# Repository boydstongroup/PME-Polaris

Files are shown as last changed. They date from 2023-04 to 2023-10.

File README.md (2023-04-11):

#Polaris PME 3D Printer Conversion Guide

This repository contains the necessary files and instructions to convert a Creality Ender-3 FFF 3D printer into an open-source Powder Melt Extrusion (PME) 3D printer.

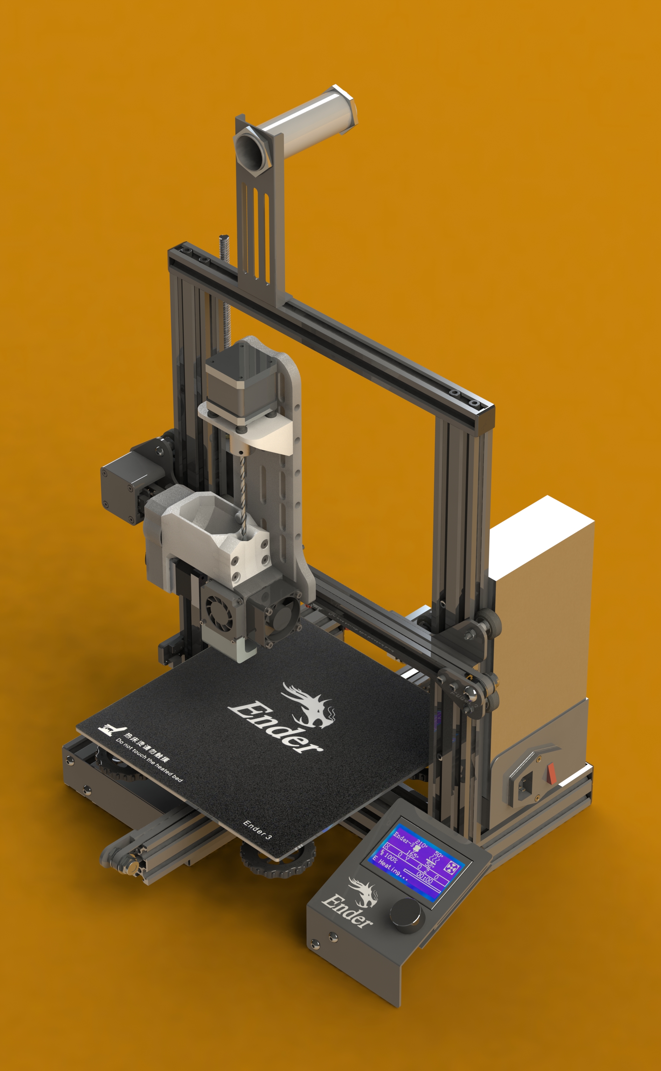
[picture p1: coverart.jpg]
PME rendering


## Table of Contents

- [Introduction](#introduction)
- [Prerequisites](#prerequisites)
- [Conversion Process](#conversion-process)
- [Contribution](#contribution)

## Introduction

The Polaris PME 3D printer enables the use of custom materials without the need for expensive filamentation processes. It also facilitates recycling and compositing of bespoke polymers with specific physical or chemical properties. The conversion process involves 3D printing custom parts, soldering electrical components, and assembling the printer. This guide aims to help researchers and enthusiasts modify a Creality Ender-3 FFF 3D printer to build an affordable and reliable PME printing system.

## Prerequisites

- Access to a functioning FFF 3D printer (for printing custom parts)
- Necessary parts and tools as specified in the bill of materials
- Basic technical knowledge (soldering, assembling, etc.)

## Conversion Process

1. Clone the [PME-Polaris repository](https://github.com/boydstongroup/PME-Polaris.git) and explore the README file for detailed information about the bill of materials and 3D models.
2. Print the custom parts using the provided 3D models.
3. Gather all necessary components and tools.
4. Follow the step-by-step conversion guide to assemble your Polaris PME 3D printer.
5. Set up the firmware and software for the printer.
6. Test and calibrate the PME 3D printer according to the provided instructions.

## Contribution

The PME project is actively developed, and contributions from the open-source community are welcome. We encourage researchers and enthusiasts to modify, improve, and share their work to advance the field of 3D printing. If you have any questions, suggestions, or improvements, please submit an issue or pull request to the [PME-Polaris repository](https://github.com/boydstongroup/PME-Polaris.git).

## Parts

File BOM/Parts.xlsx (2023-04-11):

Necessary parts
Name: | Count: | Suggested Link:
4mm Long Wood Drill | 1 | https://a.co/d/aSQy0m2
4mm to 5mm Flexible Shaft Coupling | 1 | https://a.co/d/cc4Hip7
Nema 17 Stepper Motor | 2 | https://a.co/d/9WOH7OL
M3 Rubber Damper | 4 | https://a.co/d/5EjhD60
M3x20mmMale to Female Brass Spacer | 2 | https://a.co/d/1yBfoaK
Arduino UNO R3 | 1 | https://a.co/d/0CqywGE
12mm 5V Active Piezo Buzzer | 1 | https://a.co/d/2qRS85m
I2C 1602 LCD Display Screen | 1 | https://a.co/d/4X4S6Zm
8 Pins Single Row Female Pin Headers | 2 | https://a.co/d/d53gv55
40 pin Breakable Pin Header | 1 | https://a.co/d/14hLw99
360 Degree Rotary Encoder Module | 1 | https://a.co/d/fJl5Fw0
24 Guage Stranded Wire | 1 | https://a.co/d/fuGj1Qd
Flat Hex Head Socket Cap Screw Set | 1 | https://a.co/d/faBjhD9
TMC2208 V3.0 UART Stepper Motor Driver | 1 | https://a.co/d/iA32h1T
Housing JST-XH Adapter Cable Connector | 1 | https://a.co/d/9sgeJjN
Optional parts
Brass Hot Melt Insert Nut M3 X D5.0 X L5.0 | 1 | https://www.aliexpress.us/item/2255800575168491.html
Brass Hot Melt Insert Nut M5 X D7.5 X L6.0 | 1 | https://www.aliexpress.us/item/2255800046675771.html
Brass Hot Melt Insert Nut M4 X D6.5 X L5.0 | 1 | https://www.aliexpress.us/item/2255800046610840.html

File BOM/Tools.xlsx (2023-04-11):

Tools Needed
Name: | Count: | Suggested Link:
Wire Striper | 1 | https://a.co/d/3l9bF0m
Soldering Station | 1 | https://a.co/d/aezHilF
Dupont Crimping Tool | 1 | https://a.co/d/5Vnow3Y
Cordless Screwdriver | 1 | https://a.co/d/0wc9lvD

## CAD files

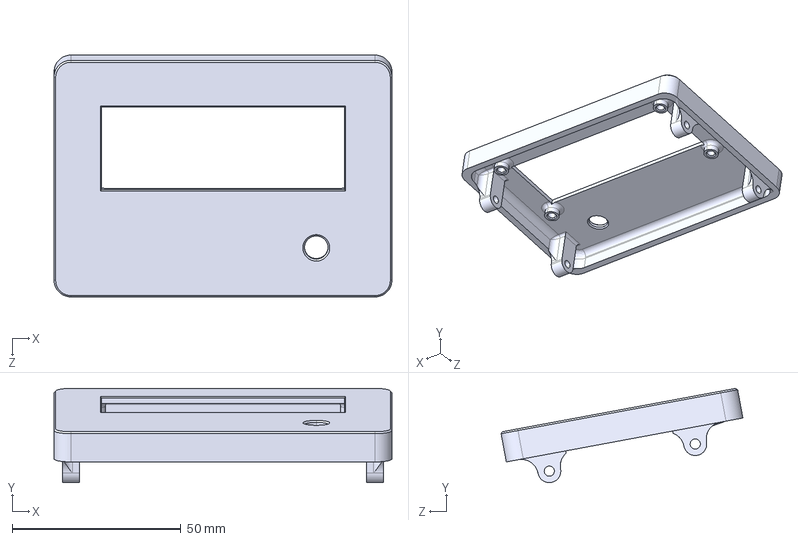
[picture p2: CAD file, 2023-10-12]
CAD/Electronics/STEP/Case Cover.STEP
100.0 x 27.9 x 71.6 mm

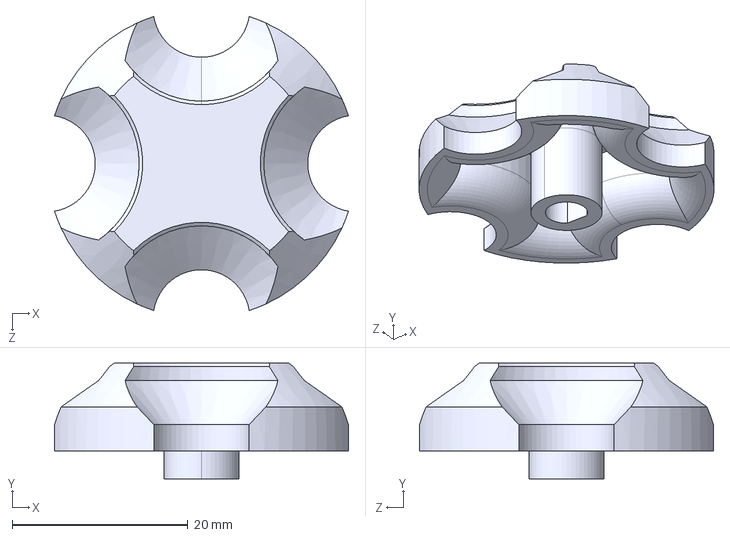
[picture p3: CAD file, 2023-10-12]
CAD/Hardware/STEP/Common/Thumb Wheel.STEP
33.5 x 13.2 x 33.5 mm

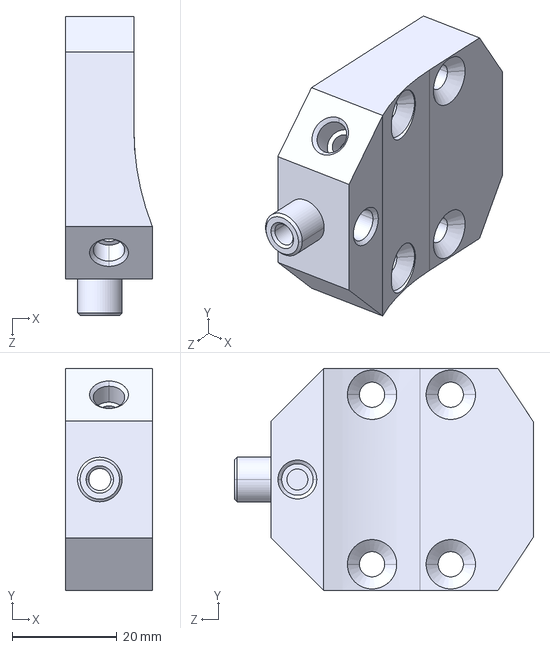
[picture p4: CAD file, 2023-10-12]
CAD/Hardware/STEP/Non Threaded/Extrusion Chamber.STEP
16.5 x 42.3 x 57.0 mm

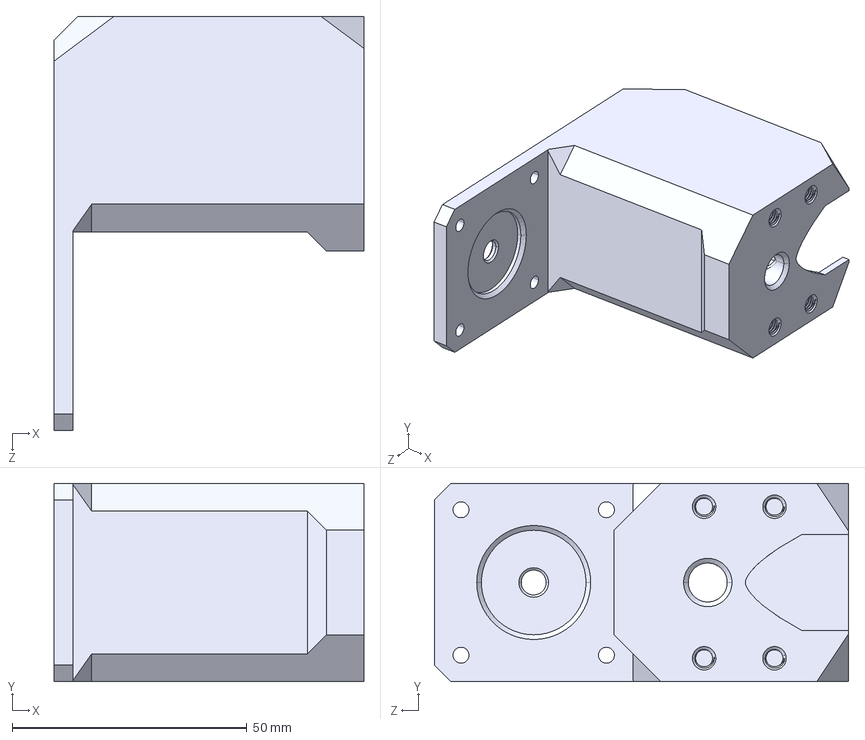
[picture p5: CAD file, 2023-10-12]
CAD/Hardware/STEP/Threaded/Powder Receptacle.STEP
66.0 x 42.3 x 88.2 mm

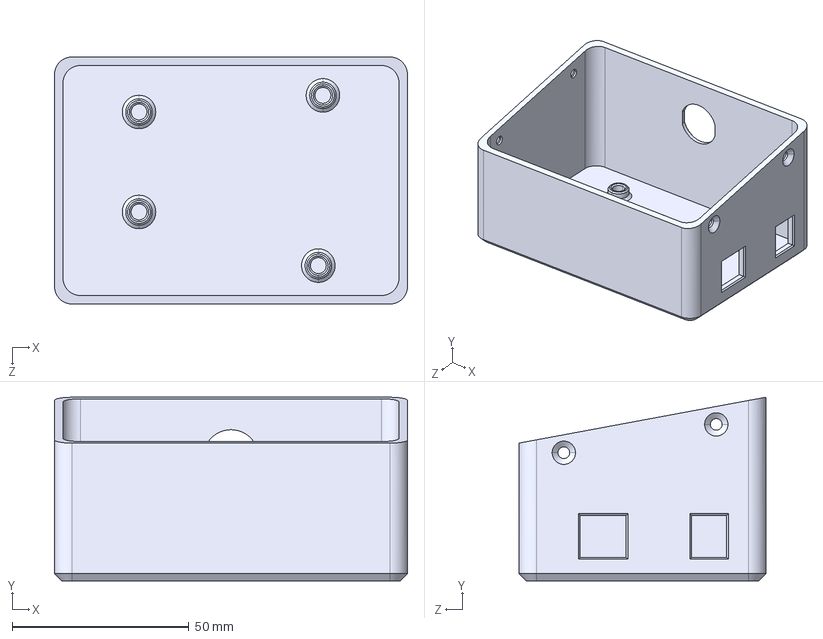
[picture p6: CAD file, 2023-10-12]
CAD/Electronics/STEP/Case Body.STEP
100.0 x 52.0 x 70.0 mm

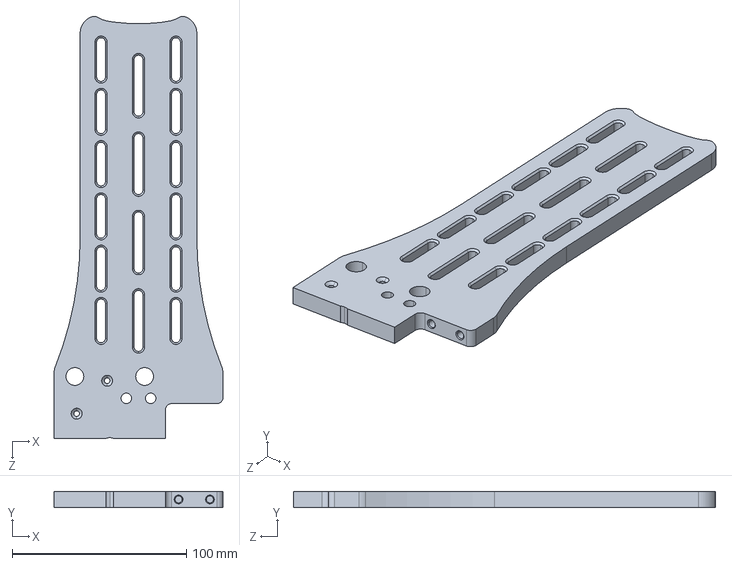
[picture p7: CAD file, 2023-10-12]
CAD/Hardware/STEP/Common/Unified Mount.STEP
97.0 x 9.35 x 242.2 mm

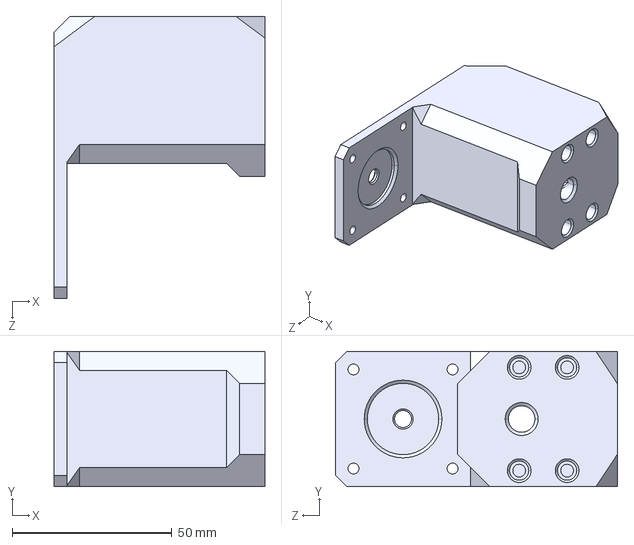
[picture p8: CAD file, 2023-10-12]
CAD/Hardware/STEP/Non Threaded/Powder Receptacle.STEP
66.0 x 42.3 x 88.2 mm

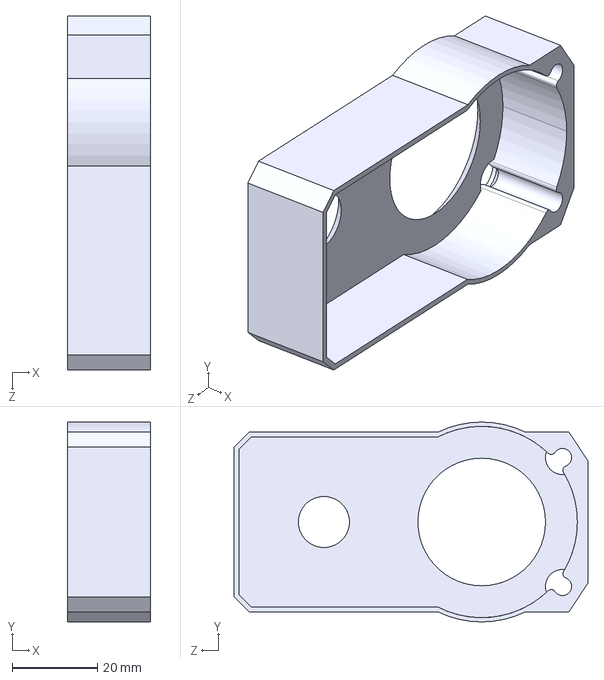
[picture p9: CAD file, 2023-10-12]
CAD/Hardware/STEP/Common/Drive Shroud.STEP
19.5 x 47.0 x 83.2 mm

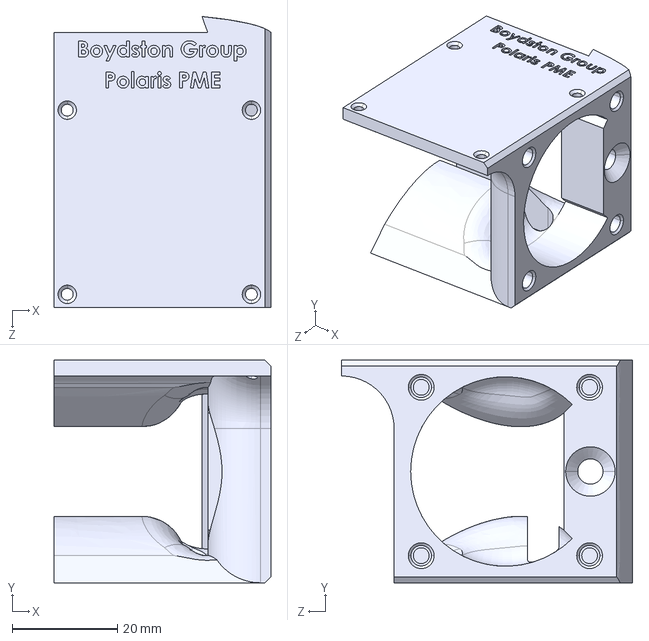
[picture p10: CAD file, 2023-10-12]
CAD/Hardware/STEP/Non Threaded/Fan Shroud.STEP
41.2 x 42.3 x 55.3 mm

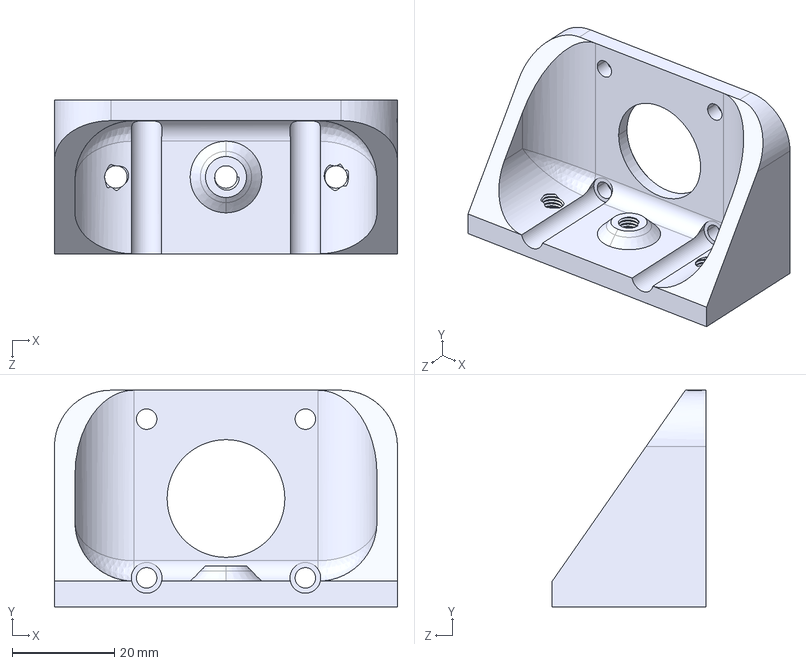
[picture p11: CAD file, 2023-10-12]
CAD/Hardware/STEP/Threaded/Motor Bracket.STEP
67.0 x 42.3 x 30.0 mm

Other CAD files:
CAD/Hardware/STEP/Threaded/Extrusion Chamber.STEP
CAD/Hardware/STEP/Non Threaded/Motor Bracket.STEP
CAD/Electronics/STL/Case Body.STL

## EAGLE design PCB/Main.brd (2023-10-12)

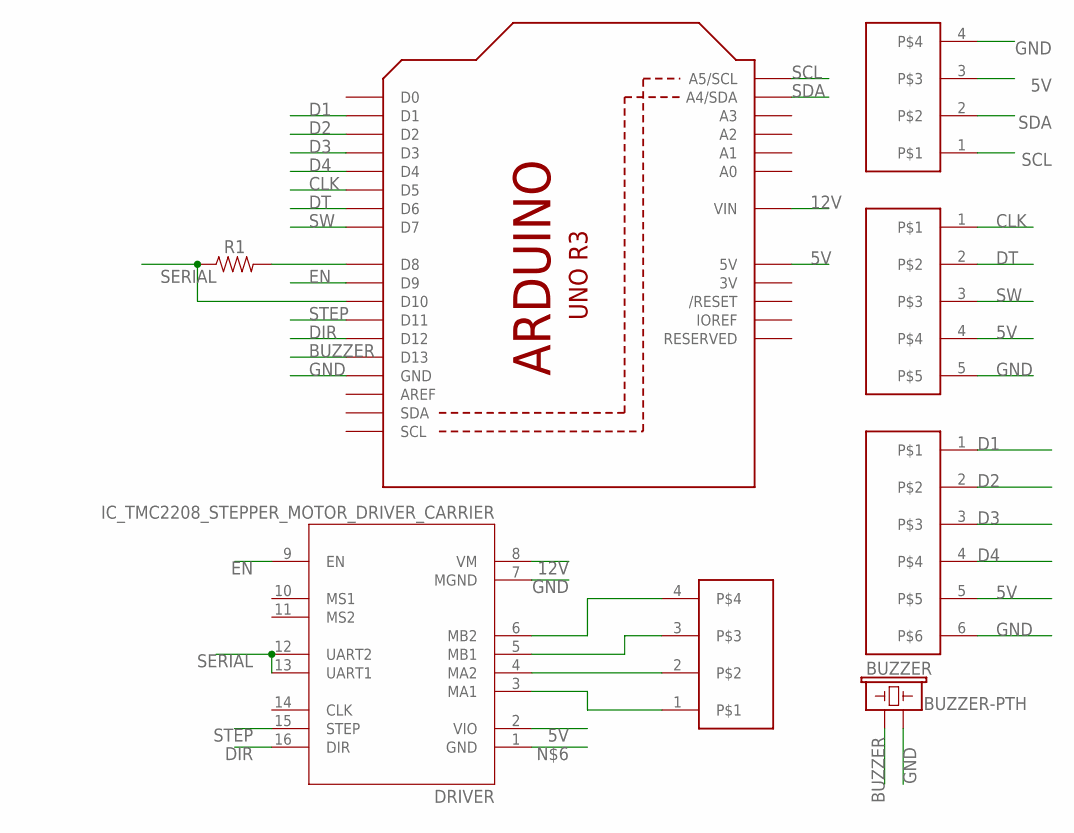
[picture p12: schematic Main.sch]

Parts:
BUZZER: BUZZER-PTH; BUZZER-12MM
DISPLAY: JST-XH-04-PIN-LONG-PAD; JST-XH-04-PACKAGE-LONG-PAD
DRIVER: IC_TMC2208_STEPPER_MOTOR_DRIVER_CARRIER
ENCODER: JST-XH-05-PIN-LONG-PAD; JST-XH-05-PACKAGE-LONG-PAD
MOTOR: JST-XH-04-PIN-LONG-PAD; JST-XH-04-PACKAGE-LONG-PAD
OUTPUT: JST-XH-06-PIN-LONG-PAD; JST-XH-06-PACKAGE-LONG-PAD
R1: AXIAL-0.3
U2: ARDUINOR3-BPLACE

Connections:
3V: U2.3V
5V: DISPLAY.3, DRIVER.2 (VIO), ENCODER.4, OUTPUT.5, U2.5V
12V: DRIVER.8 (VM), U2.VIN
BUZZER: BUZZER.+ (1), U2.D13
CLK: ENCODER.1, U2.D5
D1: OUTPUT.1, U2.D1
D2: OUTPUT.2, U2.D2
D3: OUTPUT.3, U2.D3
D4: OUTPUT.4, U2.D4
DIR: DRIVER.16 (DIR), U2.D12
DT: ENCODER.2, U2.D6
EN: DRIVER.9 (EN), U2.D9
GND: BUZZER.- (2), DISPLAY.4, DRIVER.7 (MGND), ENCODER.5, OUTPUT.6, U2.GND, U2.GND1 (GND), U2.GND2 (GND)
unnamed: DRIVER.3 (MA1), MOTOR.1
unnamed: DRIVER.4 (MA2), MOTOR.2
unnamed: DRIVER.5 (MB1), MOTOR.3
unnamed: DRIVER.6 (MB2), MOTOR.4
unnamed: R1.P$2 (2), U2.D8
SCL: DISPLAY.1, U2.A5 (A5/SCL)
SDA: DISPLAY.2, U2.A4 (A4/SDA)
SERIAL: DRIVER.12 (UART2), DRIVER.13 (UART1), R1.P$1 (1), U2.D10
STEP: DRIVER.15 (STEP), U2.D11
SW: ENCODER.3, U2.D7

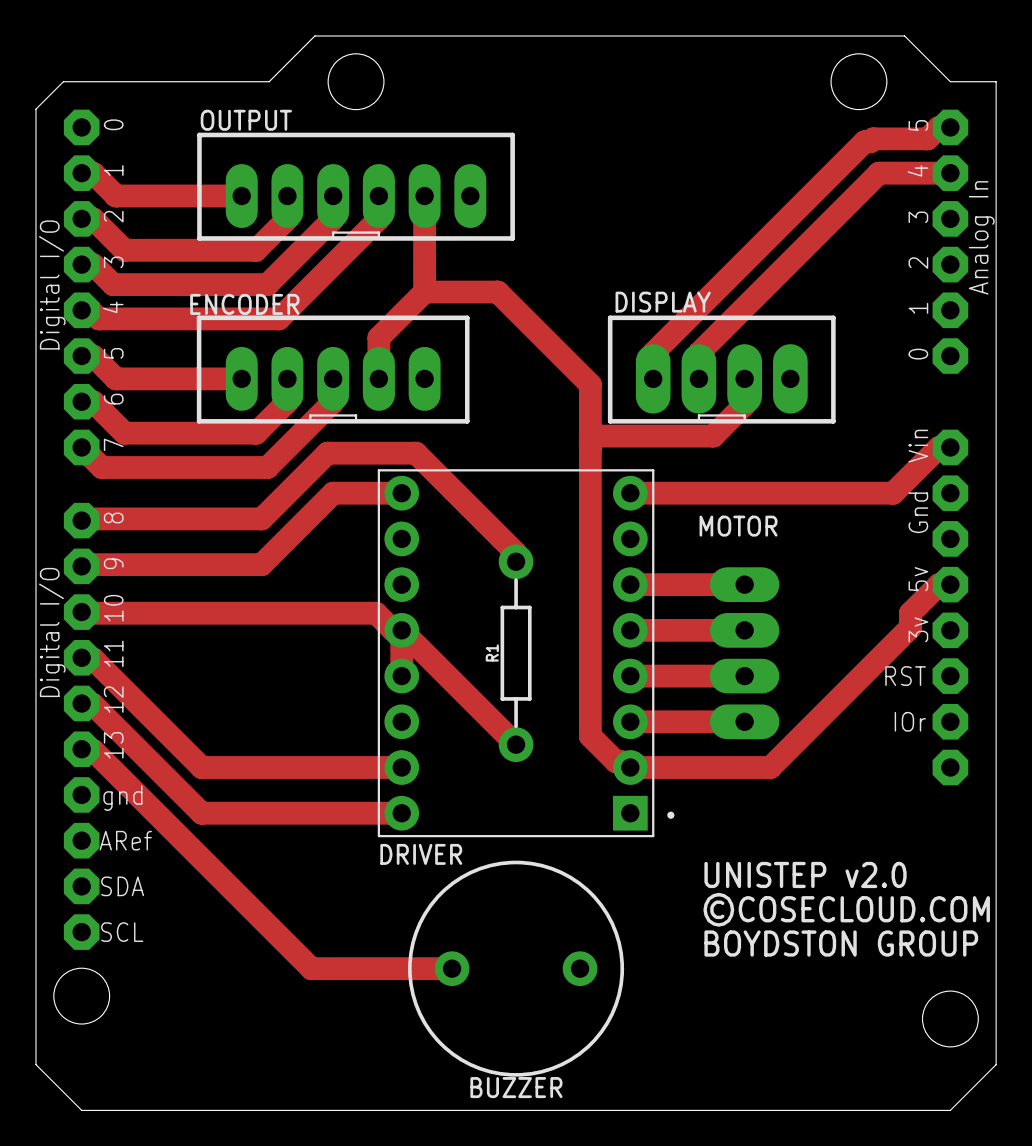
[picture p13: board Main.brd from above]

Board: 2 copper layers, 53.3 x 59.7 mm, 8 parts (1 on the bottom side), 22 nets.

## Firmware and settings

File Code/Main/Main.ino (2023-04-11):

#include <Wire.h>
#include <LiquidCrystal_I2C.h>
#include <EEPROM.h>

#if defined(ARDUINO) && ARDUINO >= 100
#define printByte(args)  write(args);
#else
#define printByte(args)  print(args,BYTE);
#endif

uint8_t arrow[8] = {0x00, 0x04, 0x06, 0x1F, 0x1F, 0x06, 0x04, 0x00};

/////Rotary Encoder Pin Assignment/////
#define rotaryPin_A 5
#define rotaryPin_B 6
#define rotaryButtonPin 7

#define EN_PIN    9  // LOW: Driver enabled. HIGH: Driver disabled
#define STEP_PIN  11  // Step on rising edge
#define RX_PIN    10  // SoftwareSerial pins
#define TX_PIN    8  //
#define DIR_PIN    12  //
#define Buzzer_PIN    13  //

#include <TMC2208Stepper.h>
TMC2208Stepper driver = TMC2208Stepper(RX_PIN, TX_PIN);

int interval = 200;
int currentLimit = 1000;
int microstep = 256;
unsigned long NextTime = 0;

unsigned int maxMenuItems;     //number of menu items
unsigned char encoder_A = 0;
unsigned char encoder_B = 0;
unsigned char encoder_A_prev = 0;
unsigned char encoder_C = 1;  //encoder button
unsigned char encoder_C_prev = 1;
unsigned long currentTime;
unsigned long loopTime;
/////End of Rotary Encoder Declarations/////

//////Menu declarations///////
unsigned int menuPos = 0; //current menu position
unsigned int lastMenuPos = 0; //previous menu position
unsigned int parentMenuPos = 0; //parent menu position
bool humanInputActive = false;  //flag to indicate if input session is active
unsigned subMenuActive = 0;   //flag to indicate a sub selection menu session is active: 0 - main menu; 1 - number selection 1- 255; 2 - binary selection yes/no; 3 - time setting;
unsigned int subMenuPos = 0;  //sub menu rotary position
unsigned int subMenuClick = 0; //sub menu click counter
unsigned long CurrentTimeS;
unsigned long CurrentTimeE;

typedef struct menu_type
{

  menu_type()
    : code(0), text("")
  {
    //do nothing
  }

  unsigned int code; //code that indicate address (position) in the menu tree
  String text; //text to be displayed for the menu selection

}  menu_type;

menu_type menu[30] = {}; //initilizing menu array, use a number >= than the number of menu options


/////End of Menu declarations////

LiquidCrystal_I2C lcd(0x27, 16, 2);

void setup() {
  menuInit();
  Serial.begin(9600);
  Wire.begin();
  rotaryEncoderInit();
  

  lcd.init();
  lcd.backlight();
  lcd.createChar(1, arrow);

  lcd.setCursor(4, 0);
  lcd.print("COSE PME");

  lcd.setCursor(5, 1);
  lcd.print("V 1.00");

  pinMode(rotaryPin_A, INPUT_PULLUP);
  pinMode(rotaryPin_B, INPUT_PULLUP);
  pinMode(rotaryButtonPin, INPUT_PULLUP);

  pinMode(Buzzer_PIN, OUTPUT);





  driver.beginSerial(115200);
  // Push at the start of setting up the driver resets the register to default
  driver.push();
  // Prepare pins
  pinMode(EN_PIN, OUTPUT);
  pinMode(STEP_PIN, OUTPUT);

  driver.pdn_disable(true);     // Use PDN/UART pin for communication
  driver.I_scale_analog(false); // Use internal voltage reference
  driver.rms_current(currentLimit);      // Set driver current = 500mA, 0.5 multiplier for hold current and RSENSE = 0.11.
  driver.toff(2);               // Enable driver in software
  driver.mstep_reg_select(true);
  driver.microsteps(microstep);
  driver.dedge(true);

  digitalWrite(EN_PIN, HIGH);    // Enable driver in hardware

  motorReset();
}

void loop() {
  //  CurrentTimeS = micros();
  rotaryEncoderUpdate();

  if (micros() < NextTime)
    NextTime = micros();

  if (micros() - NextTime > interval) {
    digitalWrite(STEP_PIN, !digitalRead(STEP_PIN));
    NextTime = micros();         // reset for next pulse
  }

}

void rotaryEncoderInit() {
  //Rotary encoder initialization
  currentTime = millis();
  loopTime = currentTime;
}

void rotaryEncoderUpdate() {

  //rotary encoder update, to be called from main loop()

  currentTime = millis();
  if (currentTime >= (loopTime + 1) ) {
    encoder_A = digitalRead(rotaryPin_A);
    encoder_B = digitalRead(rotaryPin_B);
    encoder_C = digitalRead(rotaryButtonPin);

    //handling knob rotation
    if ( (encoder_A == 0) && (encoder_A_prev == 1) ) {  //encoder changed position
      beep();

      if (encoder_B == 1) { //B is high, so encoder moved clockwise
        //Serial.println("encoder rotated CW");

        switch (subMenuActive) { //send encoder action to appropriate menu handler
          case 0: //main menu
            menuUpdate(2);
            break;

          case 1: //subMenu1
            subMenu1Update(2);
            break;

          case 2: //subMenu1
            subMenu2Update(2);
            break;

          default:
            menuUpdate(2);
            break;
        }


      } else {  //else, encoder moved counter-clockwise
        //Serial.println("encoder rotated CCW");

        switch (subMenuActive) {  //call the appropriate menuupdater depending on which sub menu is active
          case 0:
            menuUpdate(3);
            break;

          case 1:
            subMenu1Update(3);
            break;

          case 2: //subMenu1
            subMenu2Update(3);
            break;

          default:
            menuUpdate(3);
            break;
        }
      }

    }

    //handling push button
    if ( (encoder_C == 0) && (encoder_C_prev == 1) ) { //button pushed
      //Serial.println("encoder button closed.");
      longBeep();
      switch (subMenuActive) {  //call the appropriate menuupdater depending on which sub menu is active
        case 0:
          menuUpdate(1);
          break;

        case 1:
          subMenu1Update(1);
          break;

        case 2: //subMenu1
          subMenu2Update(1);
          break;

        default:
          menuUpdate(1);
          break;
      }

    } else if ( (encoder_C == 1) && (encoder_C_prev == 0) )  {  //button
      //Serial.println("encoder button opened.");

    }

    encoder_A_prev = encoder_A;
    encoder_C_prev = encoder_C;
    loopTime = currentTime;

  }

}



unsigned int menuVerifyPos(unsigned int menuCode) {
  //accepts a code that represents position in the menu
  //checks against the menu, verify it exist, and returns it
  //if the menu code given does not exist,
  //returns the closest code smaller than the one given

  bool confirmCode = false; //flag to keep track of whether code has been confirmed in menu tree

  for (unsigned int k = 0; k <= (maxMenuItems - 1); k++) {

    if (menuCode == menu[k].code) {  //found exact code, returns it
      menuPos = menu[k].code;
      confirmCode = true;
      lastMenuPos = menuCode;
      return menuPos;
    }

  }

  if (confirmCode == false) {
    menuPos = lastMenuPos;
    return menuPos;   //cannot find menu option, go back to previous menu option
  }

}

void updateMenuDisplay(unsigned int menuCode) {
  //prints menu selection to the LCD display
  //in order to have a scrolling menu effect, this code looks at item before and after current menu item and display them in a row


  String curMenu;
  String nextMenu;

  curMenu = findMenuTextFromCode(menuCode);
  nextMenu = findMenuTextFromCode((menuCode + 1));

  //starts printing to LCD
  lcd.clear();
  lcd.setCursor(0, 0);
  lcd.printByte(1);
  //char index, row index, on LCD
  lcd.print(curMenu);

  lcd.setCursor(1, 1);
  lcd.print(nextMenu); //print the next menu text in the 3rd row
}

String findMenuTextFromCode(unsigned int menuCode) {
  //accepts a code representing the code in menu, and returns the corresponding text

  for (unsigned int j = 0; j <= (maxMenuItems - 1); j++ ) {
    if (menuCode == menu[j].code) {
      return menu[j].text;
      break;
    }
  }
}

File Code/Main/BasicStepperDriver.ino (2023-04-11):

void motorReset()
{
  digitalWrite(EN_PIN, HIGH);
  int interval = 200;
  int microstep = 256;
  driver.microsteps(microstep);
  saveSettings();
}

void readSettings()
{
  int address = 0;
  interval = (EEPROM.read(address) << 8) + EEPROM.read(address + 1);

  if (interval == 0)
  {
    interval = 200;
  }
}

void saveSettings()
{
  int address = 0;

  EEPROM.write(address, interval >> 8);
  EEPROM.write(address + 1, interval & 0xFF);
}

void beep()
{
  digitalWrite(LED_BUILTIN, HIGH);
  delay(1); 
  digitalWrite(LED_BUILTIN, LOW);
}

void longBeep()
{
  digitalWrite(LED_BUILTIN, HIGH);
  delay(20); 
  digitalWrite(LED_BUILTIN, LOW);
}

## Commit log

2022-06-28 Threaded STL updated
    [Extrusion Chamber.STL, Motor Mount.STL, Pulley Shroud.STL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]
2023-10-12 CAD Update
    [Case Body.STEP, Case Body.STL, Case Cover.STEP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]

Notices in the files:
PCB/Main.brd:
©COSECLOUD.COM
